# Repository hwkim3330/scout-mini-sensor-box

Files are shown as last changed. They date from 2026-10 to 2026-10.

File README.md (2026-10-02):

# SCOUT MINI OMNI Sensor / Compute Enclosure (KETI)

Single-source parametric CAD for a hexagonal sheet-metal box that sits on an AgileX **SCOUT MINI (OMNI)** robot and carries an **Ouster OS1** lidar, a **Jetson AGX Orin**, up to six **Arducam B0473** cameras, and the power/CAN electronics. REV 9 is the final version sent out for quotation (RFQ).

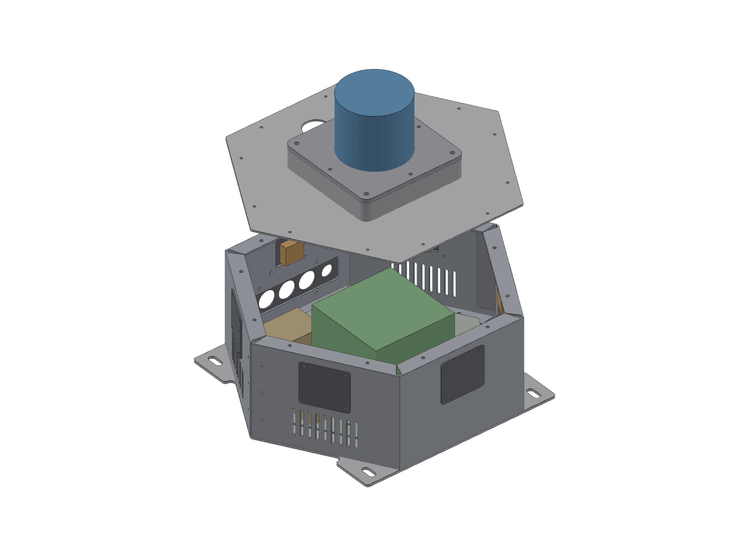
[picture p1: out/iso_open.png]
Exploded view


| | |
|---|---|
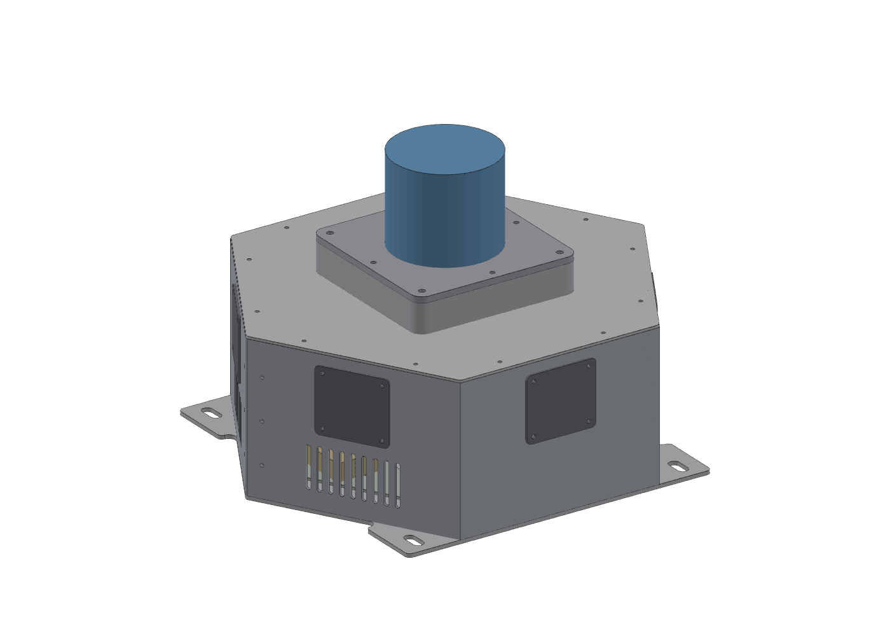
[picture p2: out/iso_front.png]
Front
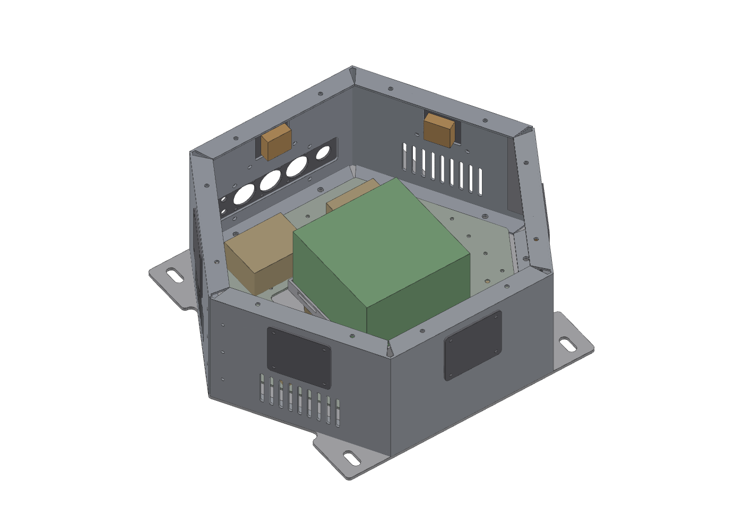
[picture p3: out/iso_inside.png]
Inside
|  |  |

## Design at a glance

- Hexagon 300 mm across flats, 130 mm tall; AL5052-H32 sheet (2 mm walls/cover, 3 mm floor), AL6061-T6 for the lidar plate and riser.
- Walls are two bent halves (C1–C3, C4–C6) joined by splice brackets, so each half fits a standard press brake.
- Self-clinching (PEM) fasteners throughout; bend allowances use Ri 2.0 / K 0.40, and the vendor re-flattens with their own bend deduction before cutting.
- Vents on C1/C3/C4/C6 for the AGX airflow, rear service panel on C5, removable electrical plate (P10).
- Sources for the mounting, power and thermal decisions are in [REFERENCES.md](REFERENCES.md).
- Items that depend on measuring real hardware (camera holder holes, OS1 pin pattern, rail slot pitch, DC/DC spec) are marked **HOLD**: those parts are delivered blank and finished in-house.

| Part | Name | Material / t |
|---|---|---|
| P01 | Bottom plate | AL5052 3.0 |
| P02 / P03 | Wall half, front / rear | AL5052 2.0 |
| P04 | Top cover | AL5052 2.0 |
| P05 | OS1 mount plate | AL6061 5.0 |
| P06 | Camera adapter plate (×8) | AL5052 2.0 |
| P07 | Rear service panel | AL5052 2.0 |
| P08 | AGX tray | AL5052 2.0 |
| P09 | Wall splice bracket (×2) | AL5052 2.0 |
| P10 | Electrical plate | AL5052 2.0 |
| P11 | OS1 riser frame | AL6061 25 |

## Files

`geom.py` is the only source of geometry. Everything in `out/` is generated from it:

| Script | Output |
|---|---|
| `geom.py` | all geometry: flat patterns, holes, PEM, bends |
| `model3d.py` | CadQuery 3D model → `out/step/*.step` |
| `dxfout.py` | laser-cut DXF → `out/dxf/*.dxf` (CUT / BEND / NOTE layers) |
| `drc.py` | design-rule check: PEM-to-edge and PEM-to-bend distance, hole spacing |
| `drawlib.py`, `sheets_a.py`, `sheets_b.py`, `build_pdf.py` | 10-sheet A3 drawing set → `out/SBOX_REV9_DRAWINGS.pdf` |
| `bom.py` | BOM / RFQ workbook → `out/SBOX_REV9_BOM.xlsx` |
| `shoot.py` + `web/render.html` | three.js renders → `out/*.png` (optional) |

## Rebuild

```bash
python3 -m venv .venv && . .venv/bin/activate
pip install -r requirements.txt

python3 model3d.py                          # STEP (+ out/tess.pkl for renders), ~30 s
python3 dxfout.py                           # DXF
python3 drc.py                              # must print "DRC issues: 0"
python3 build_pdf.py out/SBOX_REV9_DRAWINGS.pdf
python3 bom.py
```

Renders (optional; needs Node and Playwright):

```bash
(cd web && npm install) && pip install playwright && playwright install chromium
python3 shoot.py
```

The drawings need a Hangul font: Noto Sans CJK on Linux, Apple SD Gothic Neo on macOS, or Malgun Gothic on Windows is picked up automatically.

---

**한국어 요약:** SCOUT MINI 로봇 위에 올리는 육각 판금 센서/컴퓨트 박스(라이다 OS1, Jetson AGX Orin, 카메라 6대) 설계 소스입니다. `geom.py` 하나에서 STEP·DXF·도면 PDF·BOM이 모두 생성되고, REV 9는 견적용 최종판입니다.

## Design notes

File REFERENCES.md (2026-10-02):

# References

External material behind design decisions in REV 9, and what each one changes (or doesn't).

## Robot mounting and power

**AgileX SCOUT MINI R&D Kit Pro — user manual** ([PDF](https://static.generation-robots.com/media/scout-mini-pro-user-manual.pdf))
- The manufacturer's own sensor stack: stacked sheet-metal brackets (AGX Xavier → USB hub / USB-CAN / RealSense → voltage converters → lidar on top).
- Rail mounting: four slider nuts, two per rail, four screws. Same 4-point ear-slot method as P01.
- The manual gives no rail pitch, so **HOLD 2 stays open**.
- Power: separate 24→19 V (Xavier) and 24→12 V (lidar, hub, router) converters; the expansion port is limited to 24 V 5 A.
- CAN: USB-CAN at 500 kbps. This design uses CAN Pal on AGX J30 instead, which saves a USB port.

**Jetson AGX Orin DC input range** ([NVIDIA forum](https://forums.developer.nvidia.com/t/jeston-agx-orin-voltage-range/240687))
- The dev kit DC jack accepts 7–20 V. At 19 V the AGX draws about 3.2 A for 60 W, against 5 A at 12 V.
- Added to **HOLD 6** as an alternative: if the existing 24→12 V DC/DC can't do 8 A continuous, feed only the AGX from a separate 24→19 V converter. The 12 V rail then carries only the 5G modem (about 1 A).
- Check this against the carrier board documentation before buying a converter; the source is a forum answer.

**SCOUT MINI SolidWorks model** ([Saibts/AgileX-scout-mini-sw](https://github.com/Saibts/AgileX-scout-mini-sw), MIT)
- An unofficial model made for a ROS 2 simulation. The rails are plain blocks with no slot detail, so it can't settle the rail pitch either.
- The files are SolidWorks-only (`.SLDPRT`). If you open them in SolidWorks, the rail center distance is still only a rough cross-check.
- **HOLD 2 is released only by measuring the real robot or by the WeGo reply.**

## Lidar

**Ouster OS1 Rev7 hardware manual — mounting and thermal** ([docs](https://static.ouster.dev/sensor-docs/hw_user_manual_OS1/hw_common_sections_OS1/os1-overview.html))
- Recommends mounting on 6061 aluminium (167 W/m·K). P05 and P11 are AL6061-T6.
- Base and top should stay within +25 °C of ambient. Performance drops up to 20 % from 52 °C, and the sensor may shut down at 60 °C.
- Use a thermal pad (TIM) if the mounting surface is not flat. P05/P11 contact faces are left bare (no paint), and P11 has a 0.05 flatness callout.
- M3 screws; torque 120–146 cN·m for stainless.

## Thermal: AGX Orin in a closed box

**Orin in a sealed aluminium enclosure** ([MDPI Electronics 2026, 15(11) 2467](https://www.mdpi.com/2079-9292/15/11/2467))
- 190 × 154 × 60 mm aluminium box at MAXN, −20 to +40 °C ambient.
- A thermostat fan that turns on at 30 °C inside cut the inside-outside difference from about 30 °C to 5–7 °C.
- A real inference load (19 W) settled near 75 °C. A synthetic 36 W stress load throttled at 40 °C ambient.
- **Not in REV 9.** Candidate for REV 10: replace one exhaust vent (C1 or C6) with a 40 or 60 mm fan cutout plus a thermostat. REV 9 is the RFQ-final drawing set, so the change waits for the next revision. If the parts are already ordered, add a bolt-on fan bracket or post-machine the cutout instead.

## 360° camera layout (comparison only)

- [Stereolabs Robotics 360° Perception Kit](https://www.stereolabs.com/store/products/robotics-360-perception-kit): AGX Orin + 4 × ZED X, a commercial 360° kit.
- [360° surround view on AGX Orin](https://info-kevinjackson.medium.com/360-surround-view-camera-solution-using-nvidia-jetson-agx-orin-31d5c9511b3e): software side (stitching).

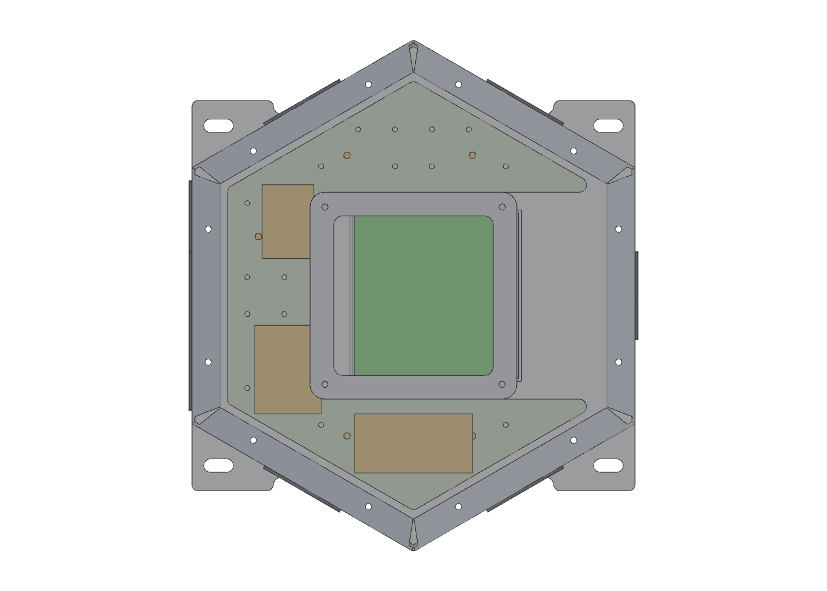
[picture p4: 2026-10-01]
out/top.png

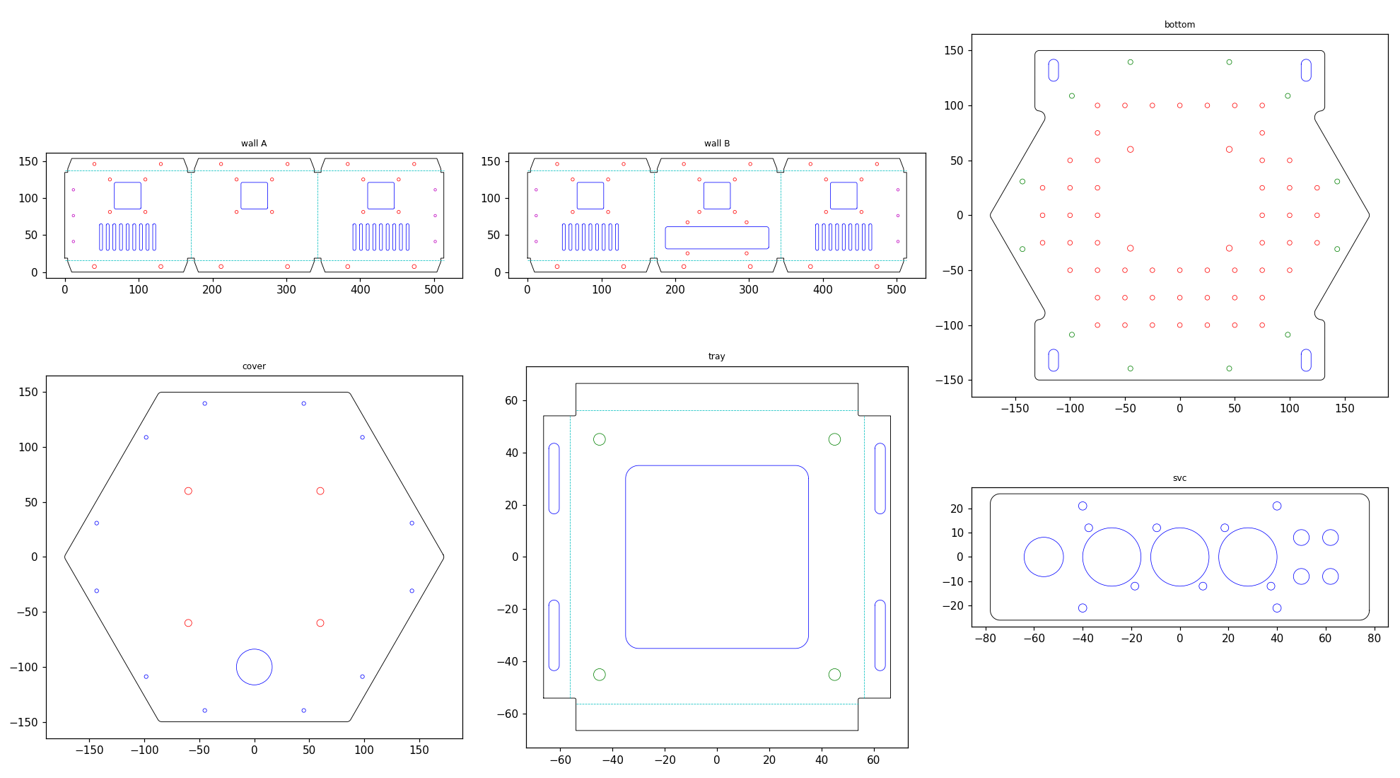
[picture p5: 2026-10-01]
out/preview.png

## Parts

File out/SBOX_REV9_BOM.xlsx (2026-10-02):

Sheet: FAB_PARTS
노란 칸 = 제작사 견적 입력. 질량 = 3D 모델 체적 × 2.68 g/cm³. 금액 = 수량 × 단가 (자동).
품번 | 품명 | 재질 | 두께 t(mm) | 수량 | 공정 | PEM / 후가공 | DXF | 단품 질량(g, 계산) | 단가 A 무처리(원) | 단가 B 분체도장(원) | 금액 A | 금액 B
P01 | BOTTOM PLATE | AL5052-H32 | 3 | 1 | Laser | CLSS-M4-2 ×10 (트레이 4 + 전장판 6), CSK ×12 | P01_BOTTOM_PLATE.dxf | 671
P02 | WALL HALF – FRONT (C1/C2/C3) | AL5052-H32 | 2 | 1 | Laser + Bend (2×60°, 2×90°) | CLSS-M3-1 ×18, CLSS-M4-1 ×6 | P02_WALL_HALF_FRONT.dxf | 394
P03 | WALL HALF – REAR (C4/C5/C6) | AL5052-H32 | 2 | 1 | Laser + Bend (2×60°, 2×90°) | CLSS-M3-1 ×22, CLSS-M4-1 ×6 | P03_WALL_HALF_REAR.dxf | 371
P04 | TOP COVER | AL5052-H32 | 2 | 1 | Laser | — (Ø5.5 ×4). 도장 시 P11 접촉부 140×140 MASK | P04_TOP_COVER.dxf | 411
P05 | OS1 MOUNT PLATE | AL6061-T6 | 5 | 1 | Laser / CNC + Tap | M5 TAP ×4 (B). OS1 접촉면 Ø100 + 하면 BARE MASK. OS1 홀 HOLD | P05_OS1_PLATE.dxf | 261
P06 | CAMERA ADAPTER PLATE | AL5052-H32 | 2 | 8 | Laser | — (lens/holder HOLD, KETI) | P06_CAMERA_PLATE.dxf | 17
P07 | REAR SERVICE PANEL | AL5052-H32 | 2 | 1 | Laser | — | P07_SERVICE_PANEL.dxf | 34
P08 | AGX TRAY | AL5052-H32 | 2 | 1 | Laser + Bend (4×90°) | CSK ×4. 70×70 = ADAPTER/CABLE CLEARANCE (HOLD 5, 그대로 가공) | P08_AGX_TRAY.dxf | 68
P09 | WALL SPLICE BRACKET | AL5052-H32 | 2 | 2 | Laser + Bend (1×60°) | — | P09_SPLICE_BRACKET.dxf | 23
P10 | ELECTRICAL PLATE (탈착식) | AL5052-H32 | 2 | 1 | Laser | — (Ø3.4 그리드, PEM 없음) | P10_ELEC_PLATE.dxf | 156
P11 | OS1 RISER FRAME | AL6061-T6 | 25 | 1 | CNC + Tap (M5 ×8, 10DP) | 무처리 BARE (도장/아노다이징 금지), 평면도 0.05 | P11_OS1_RISER.dxf (외형 참고) + 도면 SHEET 8 | 532
 | 합계 |  |  |  |  | PEM 총계 = 10 + 24 + 28 = 62 ea (REV8 114)
표면처리 [A] 무처리 / [B] 흑색 분체도장 — 열접촉면 BARE 마스킹: P05 상면 Ø100 + 하면, P11 전체 무처리, P04 상면 140×140. 공차·검사: 도면 SHEET 1, 10.

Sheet: PURCHASED
노란 칸 = 입력. 주문 수량 = 필요 + 예비 (자동). 구매처 예: 미스미코리아 / 나사몰 / 디바이스마트 / 엘레파츠.
구분 | 품목 | 규격/재질 | 필요 수량 | 예비 | 주문 수량 | 사용처 | 비고 | 단가(원) | 금액(원) | 구매처
FASTENER | M3×8 버튼헤드 (ISO 7380) | SUS304 A2 | 40 | 10 |  | 커버 12, 카메라 24, 서비스 4
FASTENER | M4×8 접시머리 육각홈 (ISO 10642) | SUS304 A2 | 16 | 4 |  | 하판 12, 트레이 4
FASTENER | M5×12 육각홈 (ISO 4762) + 평와셔 M5 | SUS304 A2 | 4 | 2 |  | P05 → P11 탭 A
FASTENER | M5×10 육각홈 (ISO 4762) + 평와셔 M5 | SUS304 A2 | 4 | 2 |  | P04 하면 → P11 탭 B | 직결 옵션 시 → P05 탭 B
FASTENER | M8×16 육각홈 (ISO 4762) + 평와셔 M8 (ISO 7089) | SUS304 A2 | 4 | 2 |  | 레일 이어 슬롯 | 규격·길이 = 레일 확인 후 (HOLD 2)
FASTENER | SCOUT 레일 T-너트 M8 | 레일 규격 따름 | 4 | 2 |  | 레일 | HOLD 2 — 레일 피치·홈 폭 확인
FASTENER | M3×10 육각홈 + M3 나일록 너트 + 와셔 | SUS304 A2 | 6 | 4 |  | D-size 커넥터 ×3
FASTENER | M4 육각 스탠드오프 M-F 25 (수 6) | Al 또는 황동 | 4 | 0 |  | AGX 트레이 | 30/35는 B0473 fit check 결과 (HOLD 5)
FASTENER | M4 육각 스탠드오프 M-F 30 / 35 | Al 또는 황동 | 8 | 0 |  | AGX 트레이 높이 조정 | 옵션
FASTENER | 블라인드 리벳 Ø3.2 돔헤드, 그립 3.0~4.8 | Al/Al | 12 | 8 |  | 벽 스플라이스 | 제작사 조립 시 제작사 지급 가능
FASTENER | M4 육각 스탠드오프 M-F 10 (수 6) | Al 또는 황동 | 6 | 2 |  | P10 전장판
FASTENER | M4×8 버튼헤드 (ISO 7380) | SUS304 A2 | 6 | 2 |  | P10 → 스탠드오프
FASTENER | M3 볼트 + 나일론 스페이서 + 나일록 너트 키트 | Nylon/SUS | 1 | 0 |  | P10 부품 (DC/DC, CAN Pal, WAGO, 5G) | M3 6~20mm
FASTENER | M3×8 육각홈 (OS1 장착) | SUS / 12.9 | 4 | 2 |  | OS1 → P05 | 길이: OS1 나사 깊이 확인 (HOLD 3)
FASTENER | M2×6 + 너트/스페이서 (카메라 모듈) | SUS | 24 | 8 |  | B0473 ×6 → P06 | HOLD 4
CONNECTOR | 케이블 글랜드 M16×1.5 + 로크너트 (클램프 4.5~10) | 니켈황동 IP68 (예: Lapp SKINTOP MS-M 16) | 1 | 1 |  | P07 — SCOUT 확장 케이블 | 케이블 외경 확인
CONNECTOR | 분할형 케이블 글랜드 M32 (커넥터 통과형) | IP54 이상 | 1 | 0 |  | P04 — OS1 케이블 | OS1 케이블 외경/커넥터 확인
CONNECTOR | etherCON 피드스루 D-size (Neutrik NE8FDP 또는 동등) | Cat6 | 1 | 0 |  | P07 D1
CONNECTOR | USB 3.0 A↔A 피드스루 D-size (Neutrik NAUSB3 또는 동등) |  | 1 | 0 |  | P07 D2
CONNECTOR | D-size 블랭크 플레이트 / 12V DC 잭 D-size |  | 1 | 0 |  | P07 D3 | 선택
CONNECTOR | SMA 벌크헤드(F) – U.FL/IPEX 피그테일 15cm | 50Ω | 4 | 0 |  | P07 SMA | 5G 모뎀 확정 후 (HOLD 7)
ELECTRICAL | SCOUT 확장 케이블: 4핀 항공 메이팅 플러그 + 4C 케이블 (AWG18 ×2 + 트위스트 CAN) 1 m | 플러그 규격 위고 확인 | 1 | 0 |  | H1 | 확보 방법 위고 문의 중 (구매 또는 KETI 납땜)
CABLE | Arducam 15-22pin FPC 60cm | Arducam 정품 | 2 | 1 |  | 먼 2면 카메라 | 기본 30cm ×6 동봉, 60cm 별도
ELECTRICAL | ATO 인라인 퓨즈홀더 AWG16~18 + ATO 5A 퓨즈 |  | 1 | 2 |  | 24V 인입 | 퓨즈 예비 2
ELECTRICAL | WAGO 221-413 레버 커넥터 | 3P | 4 | 2 |  | 24V/GND 분배
ELECTRICAL | 전선 AWG18 적/흑 | UL1015 | 3 | 0 |  | 전원 (m) | 단위 m
ELECTRICAL | 트위스트 페어 AWG24 |  | 1 | 0 |  | CAN (m) | 단위 m
ELECTRICAL | DC 배럴 플러그 5.5/2.5 피그테일 | 센터 + | 1 | 1 |  | AGX J41
ELECTRICAL | DC/DC 24→12V (기존품 사양 미달 시에만 대체) | 입력 19~36V, 12V 연속 ≥8A (예: Mean Well SD-100B-12) | 0 | 0 |  | P10 장착 | HOLD 6 — 기존품 실측 후 수량 결정
ELECTRICAL | 듀폰 점퍼 F-F 20cm |  | 4 | 4 |  | CAN Pal ↔ J30
MISC | EPDM 폼 테이프 10×3 (점착) |  | 2 | 0 |  | 커버·하판 가스켓 (m) | 옵션 방진
MISC | EPDM 패드 1t 110×110 |  | 1 | 0 |  | AGX 트레이
MISC | 벨크로 스트랩 25mm × 300 |  | 2 | 1 |  | AGX 고정
MISC | 케이블 타이 + 타이 마운트 (M3) |  | 20 | 0 |  | 하네스
MISC | 나사 고착제 중강도 (Loctite 243 등) |  | 1 | 0
OPTION | OPT-2 벤트 방진 메쉬 (SUS 100mesh, 내측 접착) |  | 4 | 0 |  | C1/C3/C4/C6 벤트 | 분진 환경 시
 | 합계

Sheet: HOLD
# | HOLD 항목 | 해제 방법 | 판금 발주 영향 | 담당 | 완료일
1 | SCOUT 4핀 항공 메이팅 플러그 규격 | 위고 문의 → 플러그+케이블 확보 후 M16 글랜드 통과 | 없음 | 위고/KETI
2 | 레일 피치 230 / 홈 폭 / T-너트 | 매뉴얼 5.2 도면·실측·위고 회신으로 확정 | P01 슬롯 가공 전 필수 | KETI
3 | OS1 4×M3 + Ø2 핀 패턴 | 보유 OS1 실측/템플릿 → P05 후가공 | P05 블랭크 납품 | KETI
4 | B0473 홀더 홀/렌즈 위치 | 납품 키트 실측 → P06 후가공 | P06 블랭크 납품 | KETI
5 | B0473 어댑터 FIT CHECK | AGX 카메라 커넥터(J509) 결합 후 하부 돌출/케이블 경로 확인 → P08 70×70 유지·축소, 스탠드오프 25/30/35 | 없음 (P08 그대로 가공) | KETI
6 | 기존 24→12V DC/DC 실물 사양 | 12V 연속 ≥8A, 피크 ≥10A, 효율 ≥90% 확인 전 전원 확정 금지. 미달 시 AGX만 24→19V 별도 변환기 가능 (AGX 입력 7~20V, 60W ≈ 3.2A) | 없음 (P10 장착) | KETI
7 | 5G 모뎀/안테나 | 모델 확정 → P10 장착, SMA 4홀 기가공 | 없음 | KETI

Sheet: RFQ
[견적 요청] KETI 모빌리티플랫폼연구센터 — SCOUT MINI 센서/컴퓨트 박스 판금 (REV 9, 최종)
1. 품목: P01~P11 (FAB_PARTS 시트), 1세트 (P06 8개, P09 2개). 옵션 수량 3세트 / 5세트 단가 병기 요청.
2. 재질: AL5052-H32 2.0T / 3.0T, AL6061-T6 5.0T (P05), AL6061-T6 25T (P11, CNC).
3. 공정: 레이저 → PEM 압입 (PennEngineering CLSS 또는 동등, 62개) → 절곡 → 벽 링 리벳 조립 (P02+P03+P09). P05/P11 탭, P11 CNC.
4. 표면: [A] 무처리, [B] 흑색 분체도장 — 분리 견적. 열접촉면 BARE: P05 상면 Ø100·하면, P11 전체, P04 140×140.
5. 첨부: 도면 PDF 10매, DXF 11종 (외형·홀 MASTER), STEP (조립/부품), 본 BOM.
6. 요청: 견적서 (A/B), 납기, 제작사 BD 반영 재전개 DXF 사전 회신, 첫 절곡품(벽 1면) 치수 확인 후 본 가공.
7. 검사: 도면 SHEET 9 출하검사 항목 (AF300±0.5, H125±0.3, 플랜지 19±0.3, PEM 전수, 가조립 체결).
8. 제외: 체결류·커넥터·장치 (PURCHASED 시트, 별도 구매). 장치 종속 홀 (HOLD) 가공 제외.
9. 문의: hwkim3@keti.re.kr

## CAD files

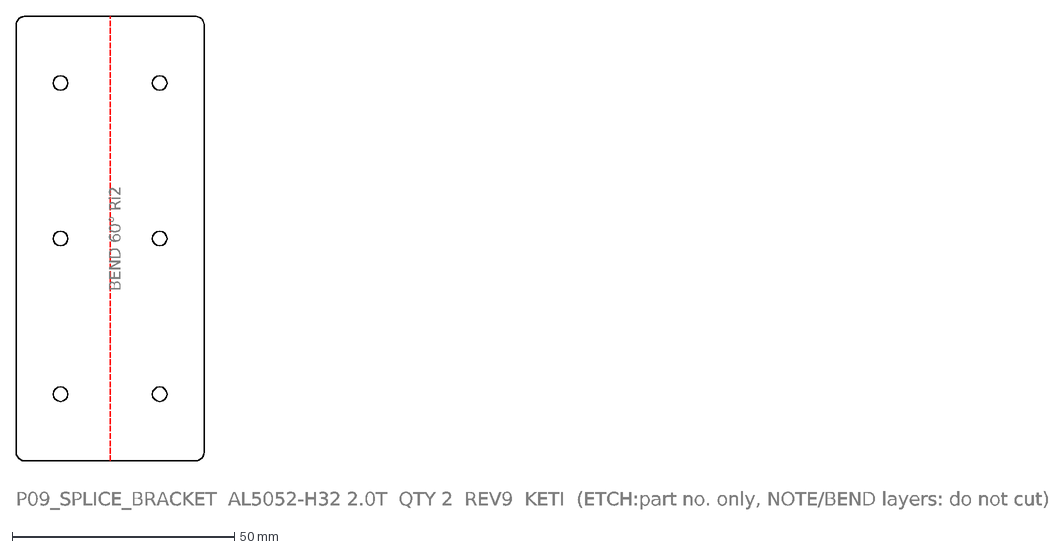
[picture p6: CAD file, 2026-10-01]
out/dxf/P09_SPLICE_BRACKET.dxf
BEND 60° Ri2
P09_SPLICE_BRACKET AL5052-H32 2.0T QTY 2 REV9 KETI (ETCH:part no. only, NOTE/BEND layers: do not cut)

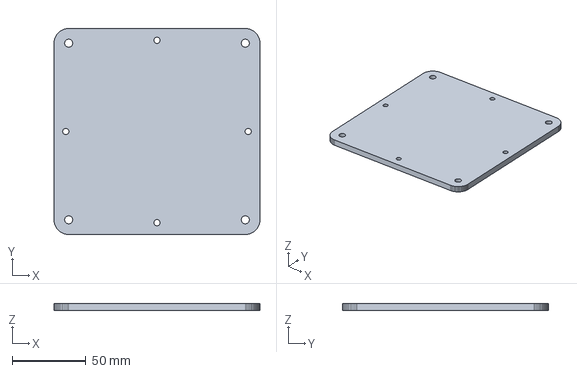
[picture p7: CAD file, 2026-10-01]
out/step/P05_OS1_PLATE.step
140.0 x 140.0 x 5.00 mm

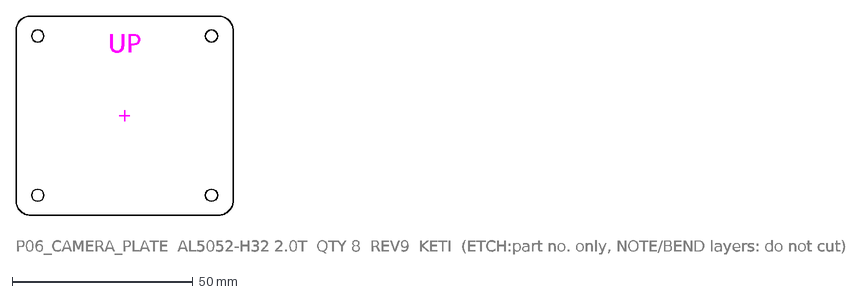
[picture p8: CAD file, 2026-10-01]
out/dxf/P06_CAMERA_PLATE.dxf
UP
P06_CAMERA_PLATE AL5052-H32 2.0T QTY 8 REV9 KETI (ETCH:part no. only, NOTE/BEND layers: do not cut)

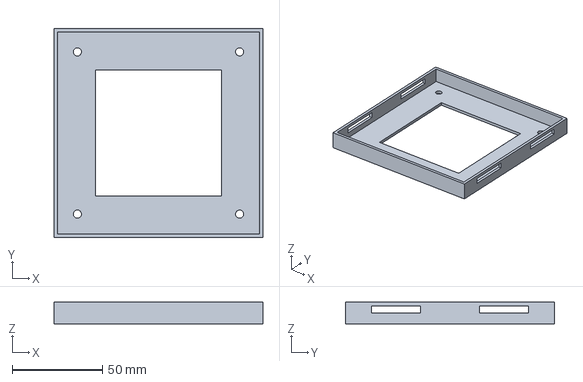
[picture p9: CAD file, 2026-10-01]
out/step/P08_AGX_TRAY.step
116.0 x 116.0 x 12.0 mm

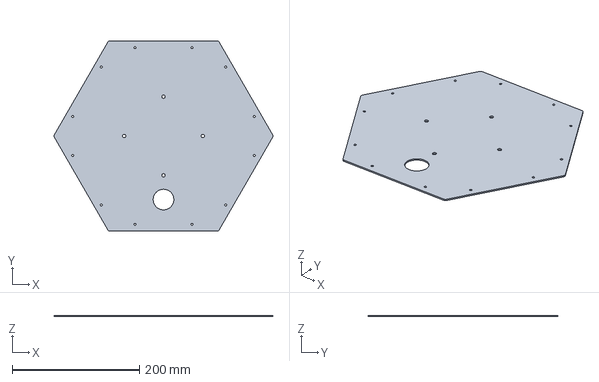
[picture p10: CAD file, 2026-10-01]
out/step/P04_TOP_COVER.step
344.6 x 299.5 x 2.00 mm

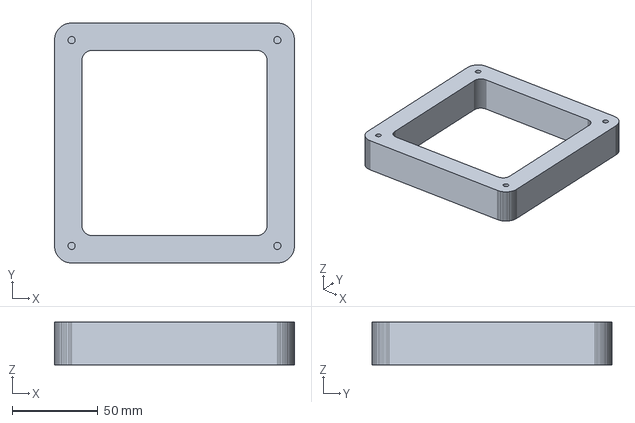
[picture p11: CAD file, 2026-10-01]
out/step/P11_OS1_RISER.step
140.0 x 140.0 x 25.0 mm

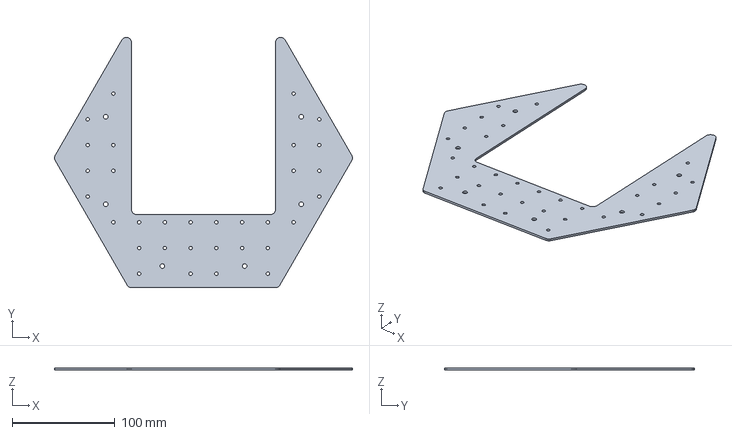
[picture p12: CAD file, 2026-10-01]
out/step/P10_ELEC_PLATE.step
289.4 x 243.1 x 2.00 mm

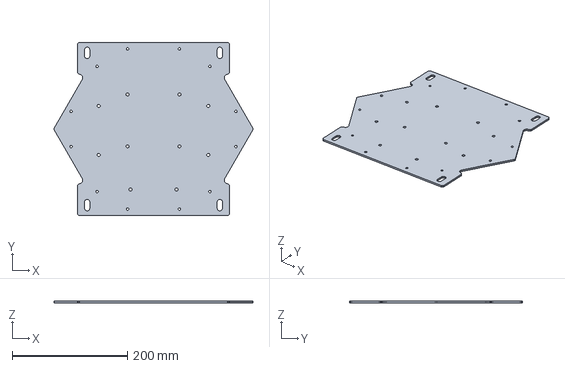
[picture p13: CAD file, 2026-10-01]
out/step/P01_BOTTOM_PLATE.step
345.2 x 300.0 x 3.00 mm

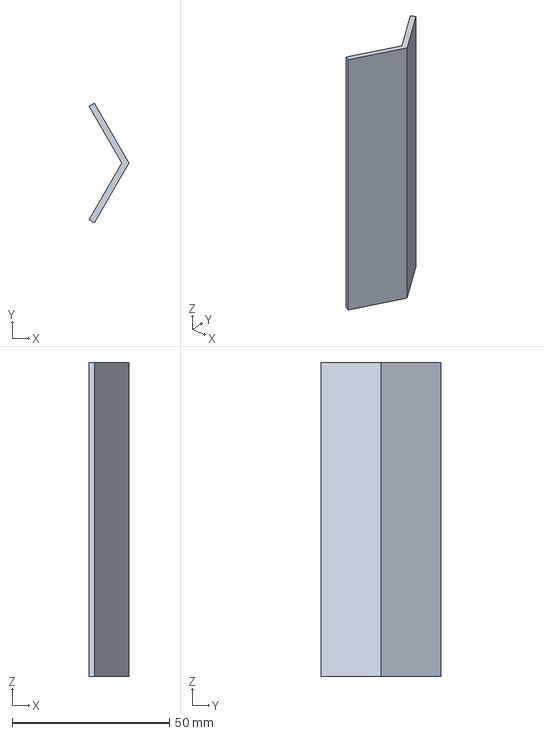
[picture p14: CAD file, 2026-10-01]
out/step/P09_SPLICE.step
12.7 x 38.1 x 100.0 mm

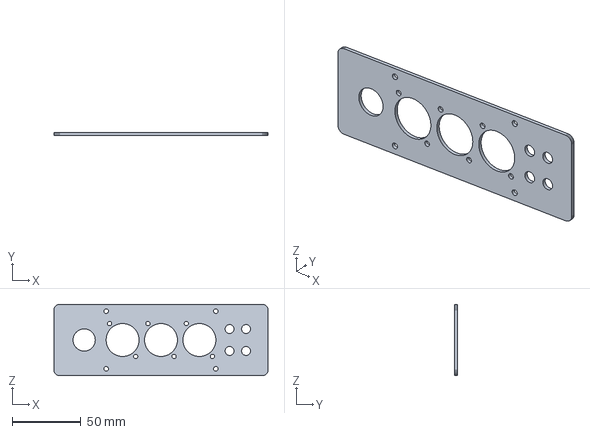
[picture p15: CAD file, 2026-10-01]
out/step/P07_SERVICE_PANEL.step
156.0 x 2.00 x 52.0 mm

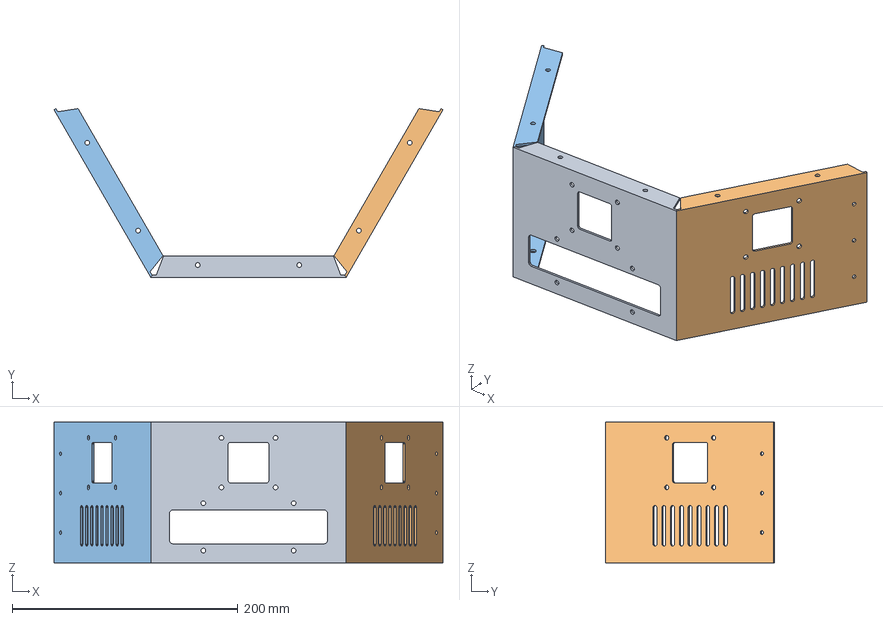
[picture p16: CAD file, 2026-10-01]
out/step/P03_WALL_HALF_REAR.step
344.9 x 149.7 x 125.0 mm

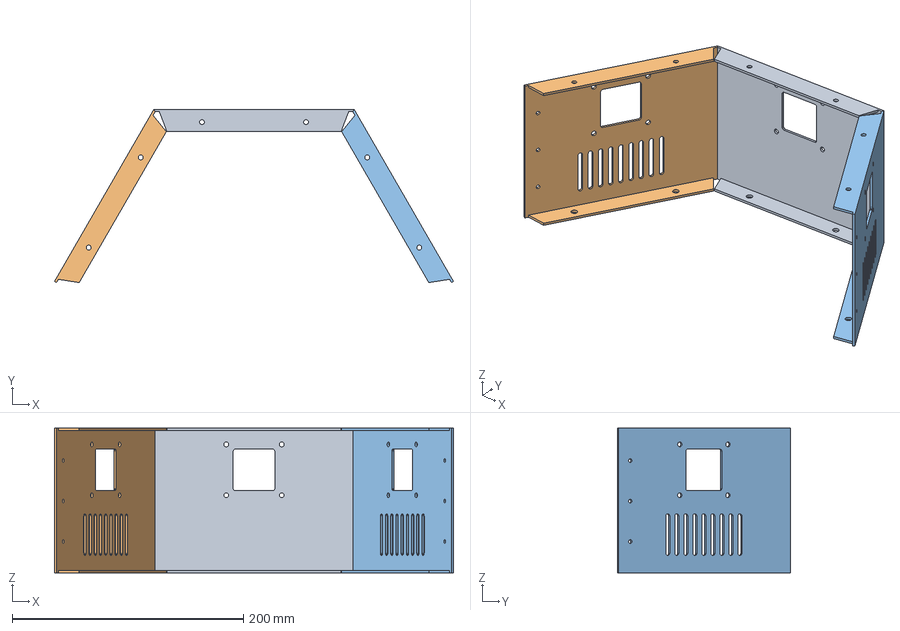
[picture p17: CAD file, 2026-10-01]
out/step/P02_WALL_HALF_FRONT.step
344.9 x 149.7 x 125.0 mm

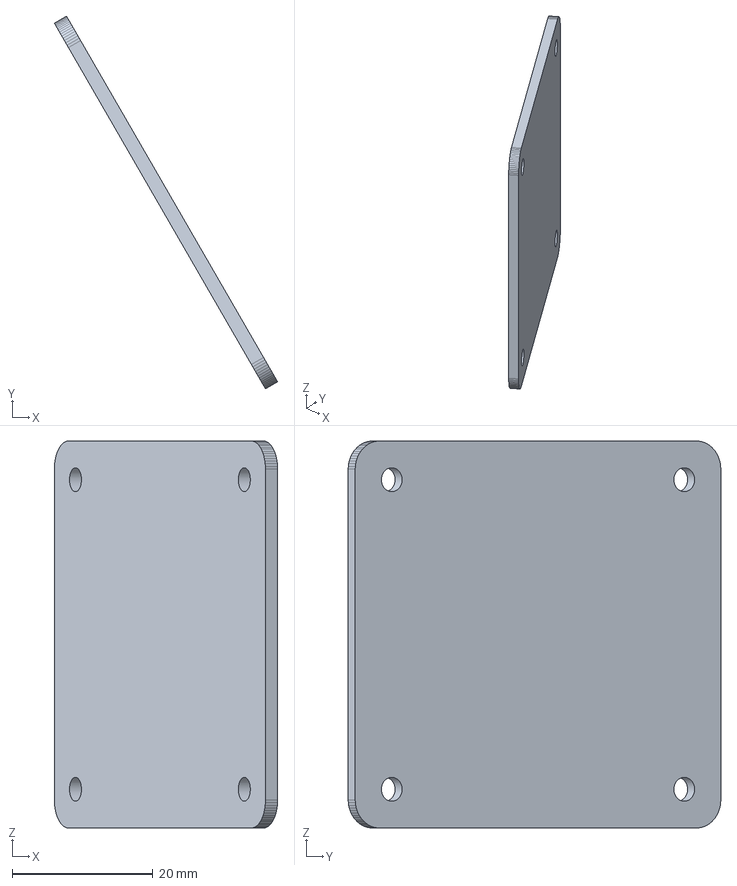
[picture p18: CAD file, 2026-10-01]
out/step/P06_CAM_PLATE.step
31.7 x 53.0 x 55.0 mm

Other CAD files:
out/dxf/P01_BOTTOM_PLATE.dxf
out/dxf/P02_WALL_HALF_FRONT.dxf
out/dxf/P03_WALL_HALF_REAR.dxf
out/dxf/P04_TOP_COVER.dxf
out/dxf/P05_OS1_PLATE.dxf
out/dxf/P07_SERVICE_PANEL.dxf
out/dxf/P08_AGX_TRAY.dxf
out/dxf/P10_ELEC_PLATE.dxf
out/dxf/P11_OS1_RISER.dxf

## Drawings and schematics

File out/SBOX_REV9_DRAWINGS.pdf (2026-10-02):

1 | 2 | 3 | 4 | 5 | 6 | 7 | 8

F

E

D

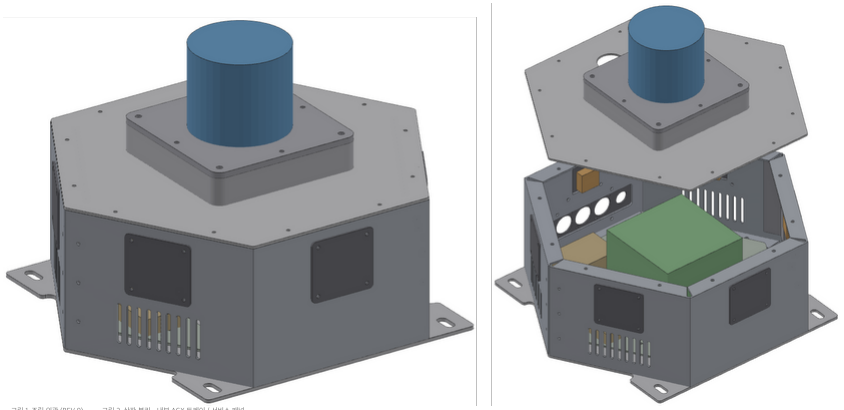
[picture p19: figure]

C

B

A

SENSOR / COMPUTE ENCLOSURE — 제작 도면 세트 (RFQ RELEASE) | SCOUT MINI OMNI / Jetson AGX Orin / Arducam B0473 / Ouster OS1

DIMENSIONS IN mm · 3RD ANGLE PROJECTION · DO NOT SCALE · DXF = MASTER FOR CUT GEOMETRY · 도면/DXF 상이 시 문의

그림 1. 조립 외관 (REV 9) | 그림 2. 상판 분리 – 내부 AGX 트레이 / 서비스 패널
품번 | 품명 | 재질 / 두께 | 수량 | 가공 | 인서트 / 표면
P01 | BOTTOM PLATE | AL5052-H32 3.0T | 1 | LASER | CLSS-M4-2 ×10, CSK ×12
P02 | WALL HALF – FRONT | AL5052-H32 2.0T | 1 | LASER + BEND 4 | CLSS-M3-1 ×18, M4-1 ×6
P03 | WALL HALF – REAR | AL5052-H32 2.0T | 1 | LASER + BEND 4 | CLSS-M3-1 ×22, M4-1 ×6
P04 | TOP COVER | AL5052-H32 2.0T | 1 | LASER | — (P11 접촉부 MASK)
P05 | OS1 MOUNT PLATE | AL6061-T6 5.0T | 1 | LASER/CNC + TAP | M5 TAP ×4, 접촉면 BARE
P06 | CAMERA ADAPTER PLATE | AL5052-H32 2.0T | 8 | LASER | — (6 + 2 spare)
P07 | REAR SERVICE PANEL | AL5052-H32 2.0T | 1 | LASER | —
P08 | AGX TRAY | AL5052-H32 2.0T | 1 | LASER + BEND 4 | CSK ×4
P09 | WALL SPLICE BRACKET | AL5052-H32 2.0T | 2 | LASER + BEND 1 | —
P10 | ELECTRICAL PLATE (탈착) | AL5052-H32 2.0T | 1 | LASER | — (Ø3.4 GRID)
P11 | OS1 RISER FRAME | AL6061-T6 25T | 1 | CNC + TAP | M5 TAP ×8, 무처리 BARE

PEM 합계 62개 (REV8 114개). 구매품 전체 목록: SBOX_REV9_BOM.xlsx

SHEET | CONTENTS
1 | INDEX / GENERAL NOTES / REVISION
2 | GENERAL ASSEMBLY (치수·인터페이스)
3 | P01 BOTTOM PLATE
4 | P02 WALL HALF – FRONT (전개/성형)
5 | P03 WALL HALF – REAR + SERVICE OPENING
6 | P04 TOP COVER / P05 OS1 PLATE
7 | P06 / P07 / P08 / P09 SMALL PARTS
8 | P10 ELECTRICAL PLATE / P11 OS1 RISER + FOV
9 | INTERNAL LAYOUT / WIRING / POWER BUDGET
10 | HARNESS / HOLD / INSPECTION / RFQ

## GENERAL NOTES / 일반 주기

1. 단위 mm. 레이저 외형·홀 좌표는 DXF가 기준(MASTER), 성형 치수·공차·후가공은 본 도면이 기준.
2. 일반공차 ISO 2768-m. 레이저 외형/홀 ±0.1, 절곡 성형치수 ±0.3, 절곡각 ±0.5°, 평면도 0.5/100.
3. 절곡 내R 2.0 (2T). DXF 전개는 K=0.40 참고치 — 제작사 금형 BD로 재전개 허용 (성형 외곽·홀 위치 유지).
4. PEM: PennEngineering CLSS(스테인리스) 또는 동등품, 절곡 전 압입. 총 62개.
5. 버 제거, 외곽 C0.3~0.5. 케이블/벤트 슬롯 버 제거 철저(FPC·케이블 손상 방지).
6. 표면: [A] 무처리 기본 견적 + [B] 흑색 분체도장 옵션 별도 견적 (PEM/탭 나사부 마스킹).

6a. 열접촉면 분체도장 금지 (BARE AL 마스킹): P05 상면 OS1 접촉부 Ø100 + P05 하면 전체,

P11 전체 무처리, P04 상면 P11 접촉부 140×140. — THERMAL CONTACT SURFACE KEEP BARE ALUMINUM

7. P02+P03+P09 리벳 조립(벽 링) 및 P01/P04 가조립 체결 확인까지 제작사 범위.
8. 장치 실측 종속 홀(OS1·카메라 홀더)은 발주 제외 — 블랭크 납품. P01 레일 슬롯은 피치 확인(HOLD 2) 후 가공.

## REVISION HISTORY

REV 8 → REV 9 변경 (견적 최종판)

a) P08 중앙 70×70: 'ADAPTER / CABLE CLEARANCE — HOLD UNTIL B0473 ADAPTER FIT CHECK'로 재정의.

REV8의 'J509 하부' 표기 삭제 (J509 = 캐리어보드 상면, 모듈 하부 영역 카메라 커넥터 — 어댑터 직결).

b) P01 M3 PEM 그리드 54개 삭제 → M4 PEM 6개 + 탈착식 전장판 P10 (Ø3.4 레이저 그리드). PEM 114 → 62.
c) OS1: P05 → P11 AL6061 25T 라이저 프레임 → P04. 하향 −22.5° 전 범위 확보 (가림 경계 −23.8°).

P04 M5 PEM 삭제 → 하면 M5 볼트. 라이저 제거 직결 옵션 유지 (P05 탭 B, 가림 경계 −15.4°).

d) P05 / P11 / P04 열접촉면 분체도장 금지 (BARE AL).
e) 전원 HOLD 6 유지 (기존 DC/DC 연속 ≥8A 확인 전 확정 금지). CAN: J30 p29/p31, CAN Pal 3.3V 구동 확정.

REV 8: 레일 슬롯 외부 이어(Y±132), 2분할 절곡 벽, HOLD 블랭크화, 서비스 패널 확정, 전원 예산

REV 7: 개념 GA / 배선 / 하네스 (제작 불가)

## 발주 범위 / SCOPE OF SUPPLY

[제작사 범위] P01~P11 레이저·절곡·CNC·탭·PEM 압입·버 제거·각인

+ 벽 링 리벳 조립(P02+P03+P09) + P01/P04 가조립 체결 확인

+ 표면처리 옵션 [B] 견적 분리 (6a 마스킹 포함)

[납품] 개별 포장, 벽 링은 조립 상태. 체결류(BOM 구매품)는 제외

[제외] 장치 종속 홀(HOLD) 후가공, 전장/하네스, 장치 조립

[제출 요청] 견적서(A/B 구분) · 납기 · 재전개 DXF(BD 반영)

- 첫 절곡품 치수 확인서(AF300, H125, 플랜지 19, 홀 피치)

[검사] SHEET 10 INSPECTION 항목 기준

KETI Mobility Platform Research Center | PROJECT: SCOUT-OMNI-SBOX

PART NO.

### ASSY-SBOX-R9

MATERIAL

see part list

QTY

1 set

SCALE

AS NOTED

TITLE

DRAWING INDEX / GENERAL NOTES

FINISH

RAW / OPT. BLACK P/C

REV

9

SHEET

DRAWN

hwkim3 / KETI

TOL.

ISO 2768-m (UNO)

DATE

2026-10-01

STATUS

RFQ FINAL

## TOP VIEW (FRONT = +Y = C2) 1:3

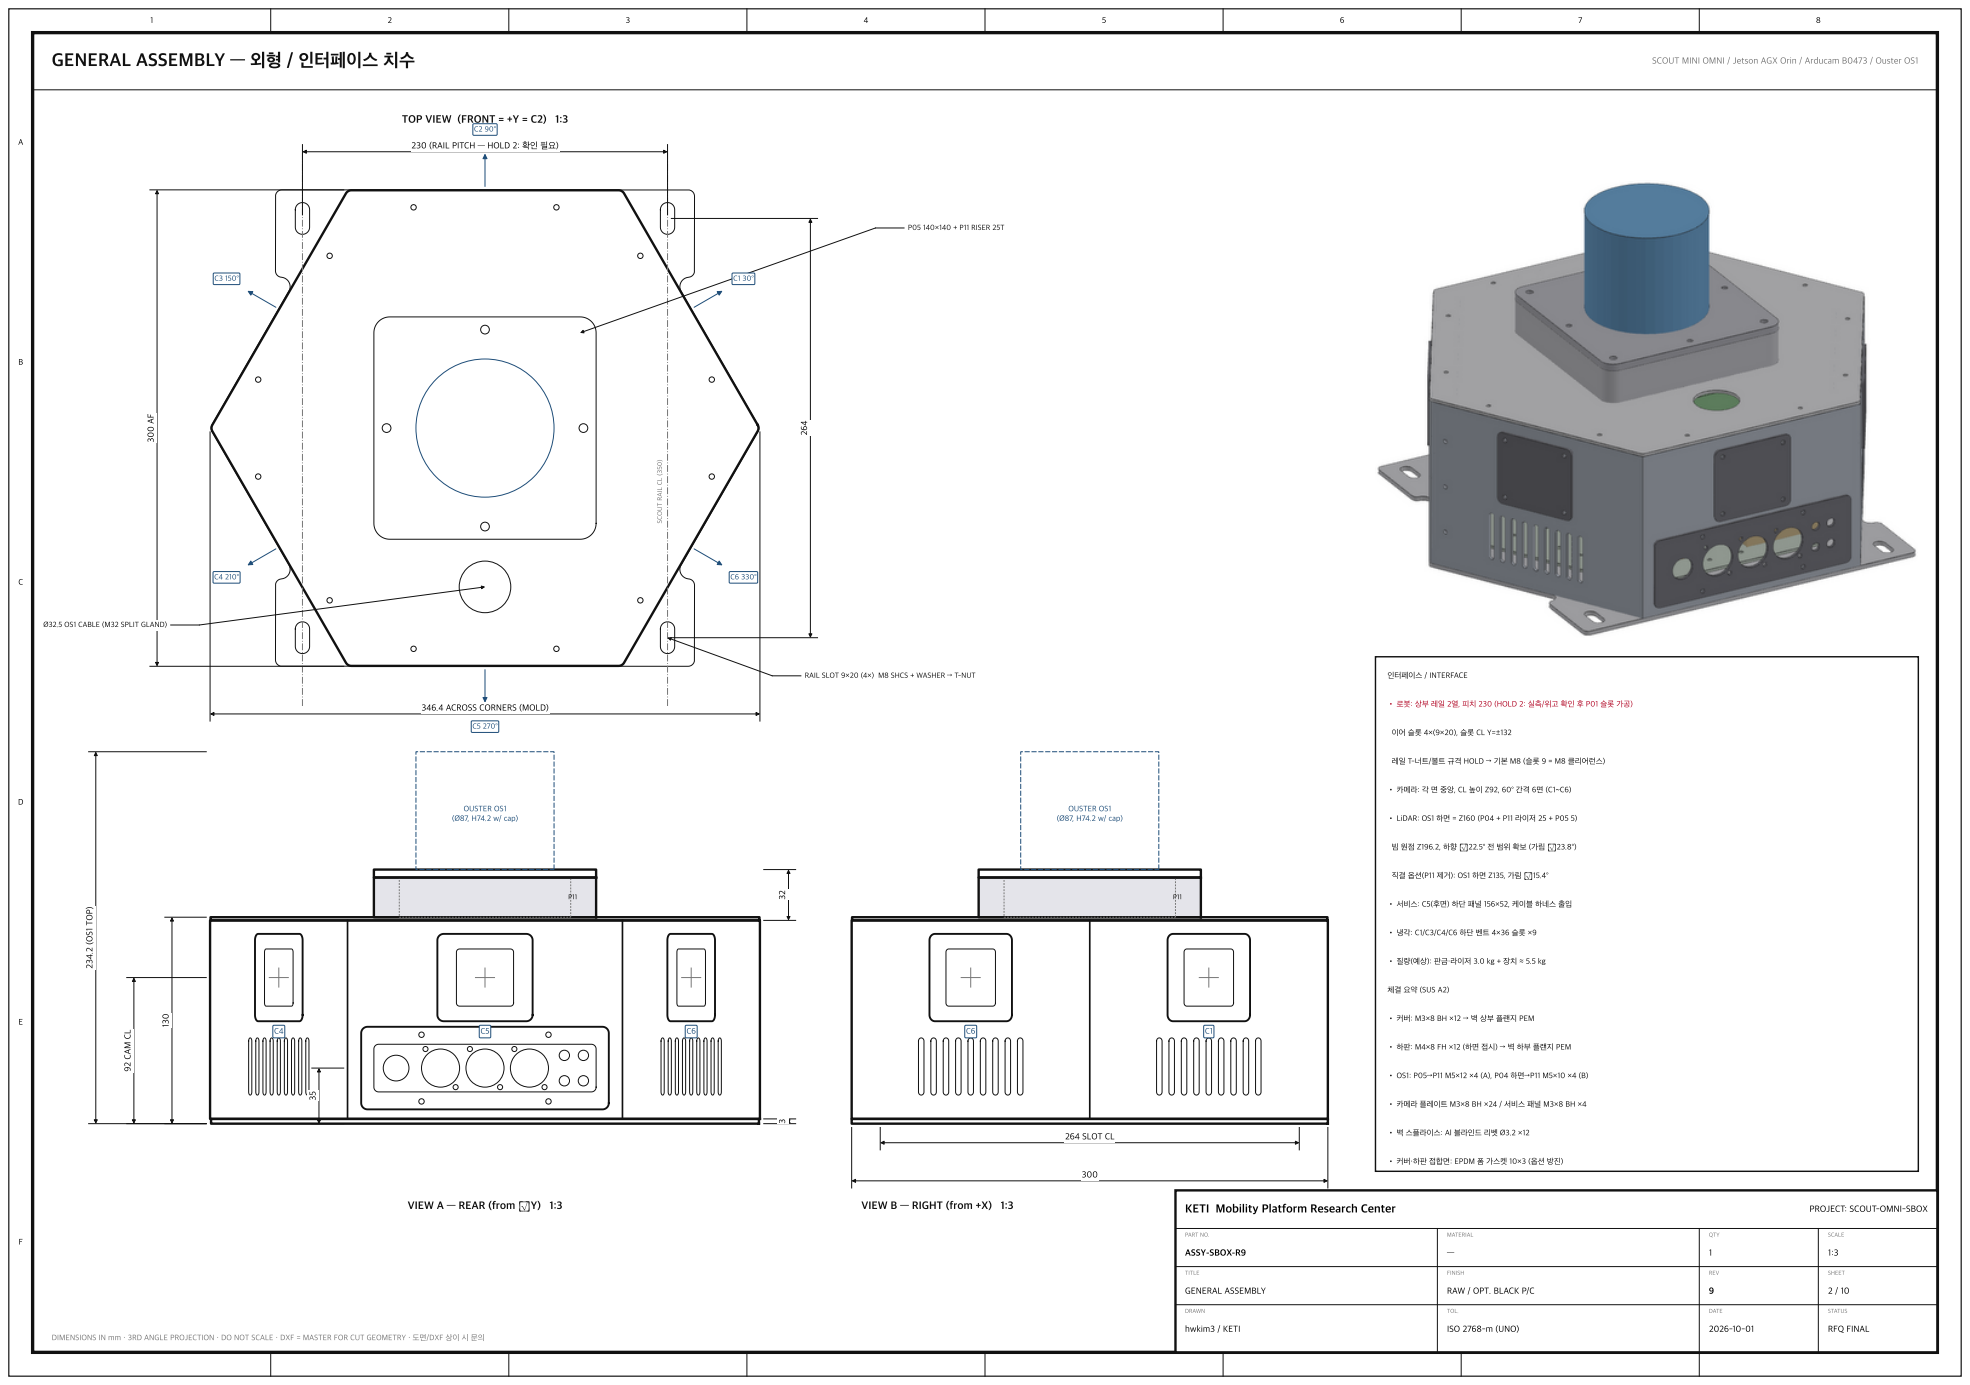
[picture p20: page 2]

230 (RAIL PITCH — HOLD 2: 확인 필요)

RAIL SLOT 9×20 (4×) M8 SHCS + WASHER → T-NUT

• 로봇: 상부 레일 2열, 피치 230 (HOLD 2: 실측/위고 확인 후 P01 슬롯 가공)

레일 T-너트/볼트 규격 HOLD → 기본 M8 (슬롯 9 = M8 클리어런스)

• 카메라: 각 면 중앙, CL 높이 Z92, 60° 간격 6면 (C1~C6)

• 서비스: C5(후면) 하단 패널 156×52, 케이블 하네스 출입

• 질량(예상): 판금·라이저 3.0 kg + 장치 ≈ 5.5 kg

• 커버: M3×8 BH ×12 → 벽 상부 플랜지 PEM

• 하판: M4×8 FH ×12 (하면 접시) → 벽 하부 플랜지 PEM

• 카메라 플레이트 M3×8 BH ×24 / 서비스 패널 M3×8 BH ×4

• 벽 스플라이스: Al 블라인드 리벳 Ø3.2 ×12

• 커버·하판 접합면: EPDM 폼 가스켓 10×3 (옵션 방진)
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

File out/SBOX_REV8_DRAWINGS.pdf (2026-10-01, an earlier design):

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

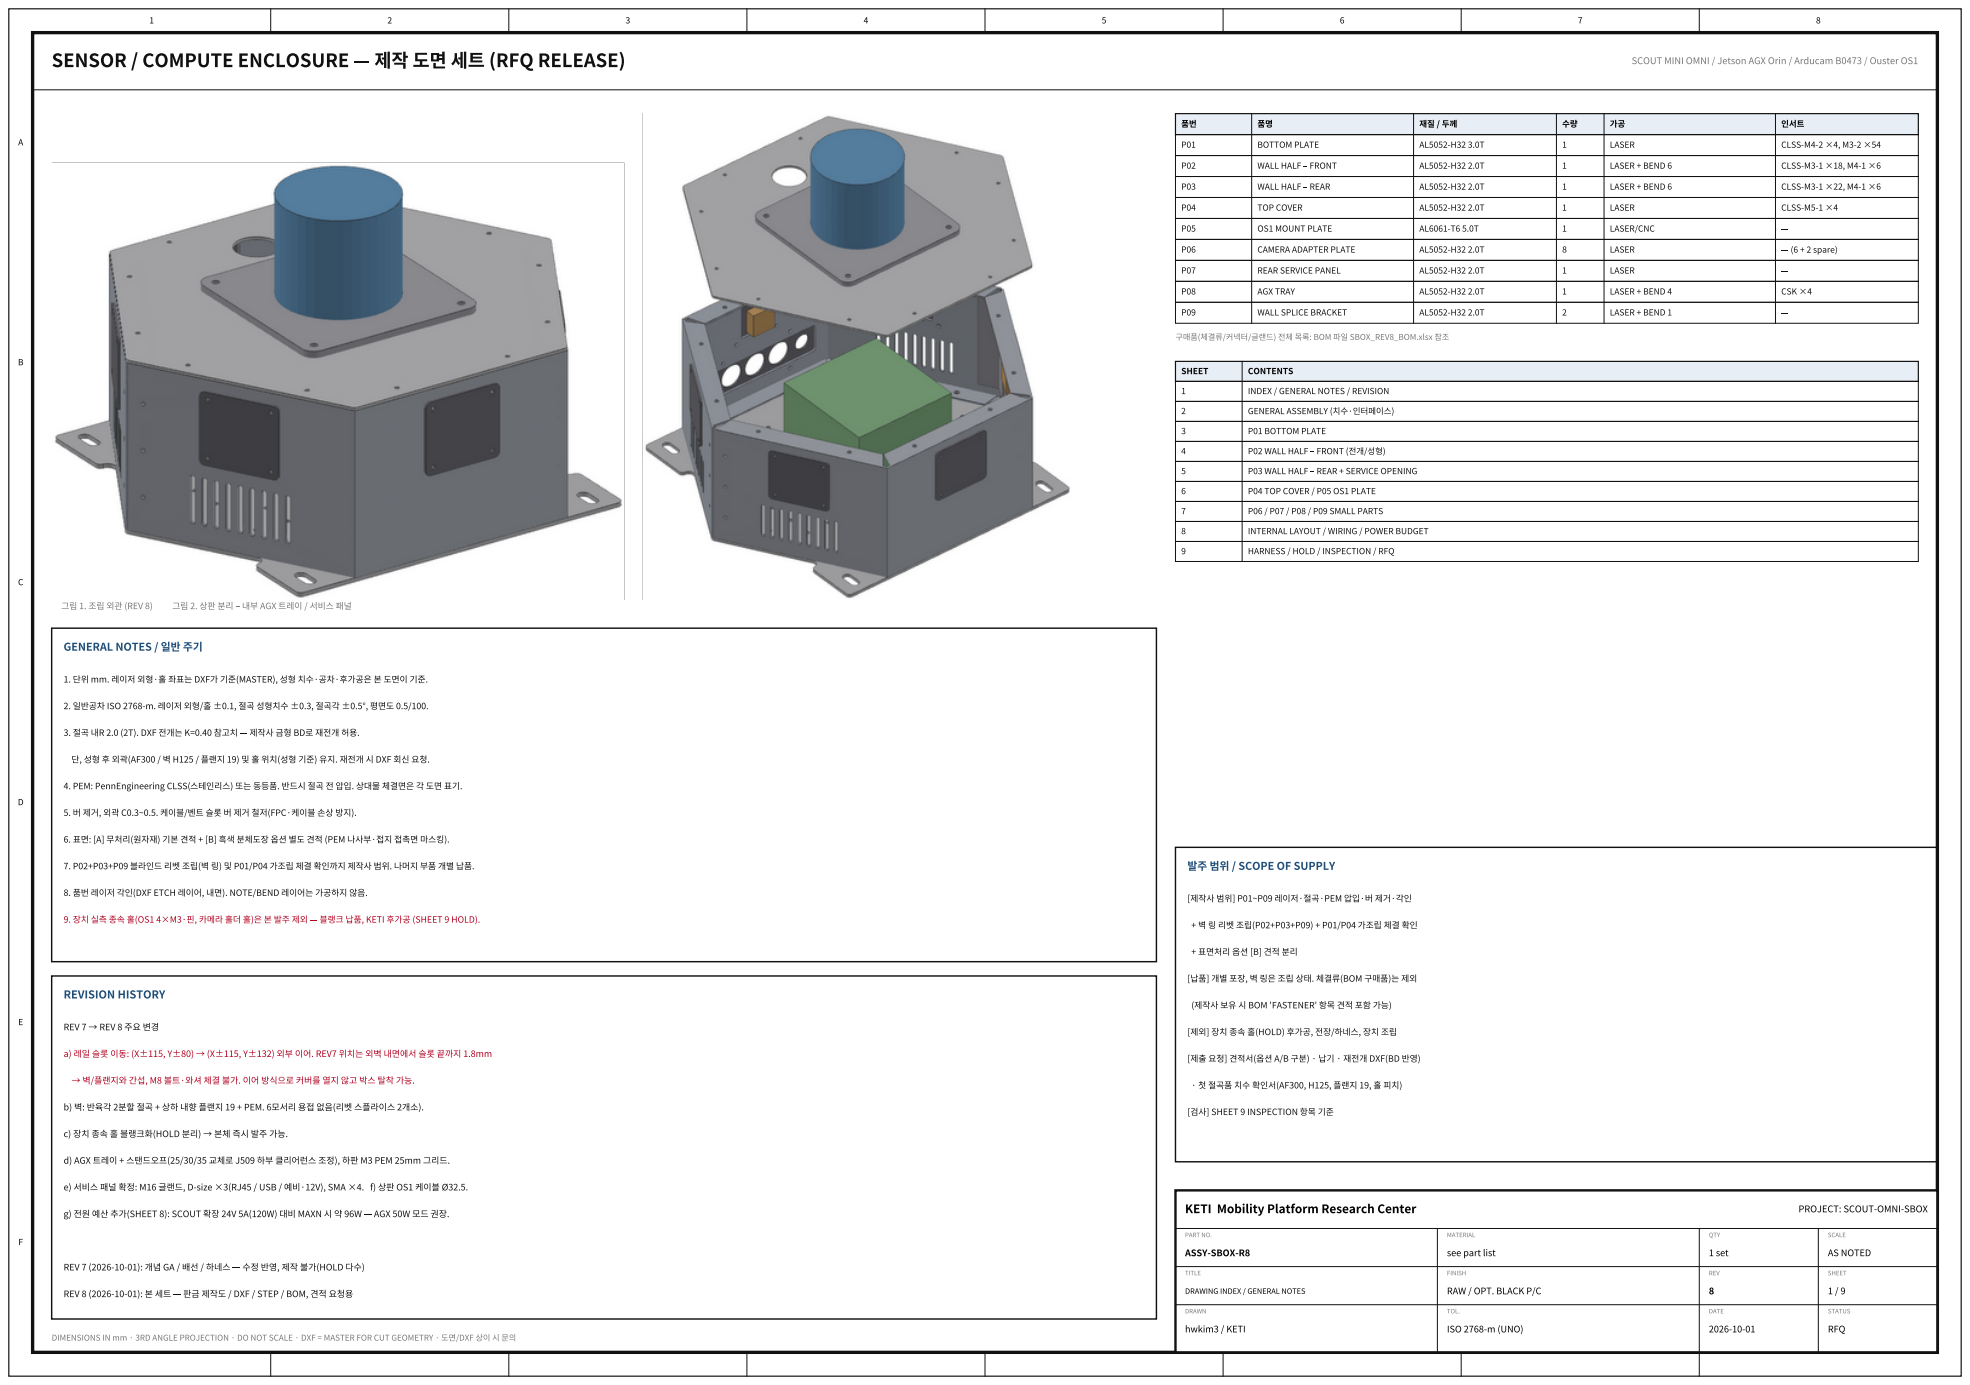
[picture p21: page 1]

# TOP VIEW (FRONT = +Y = C2) 1:3

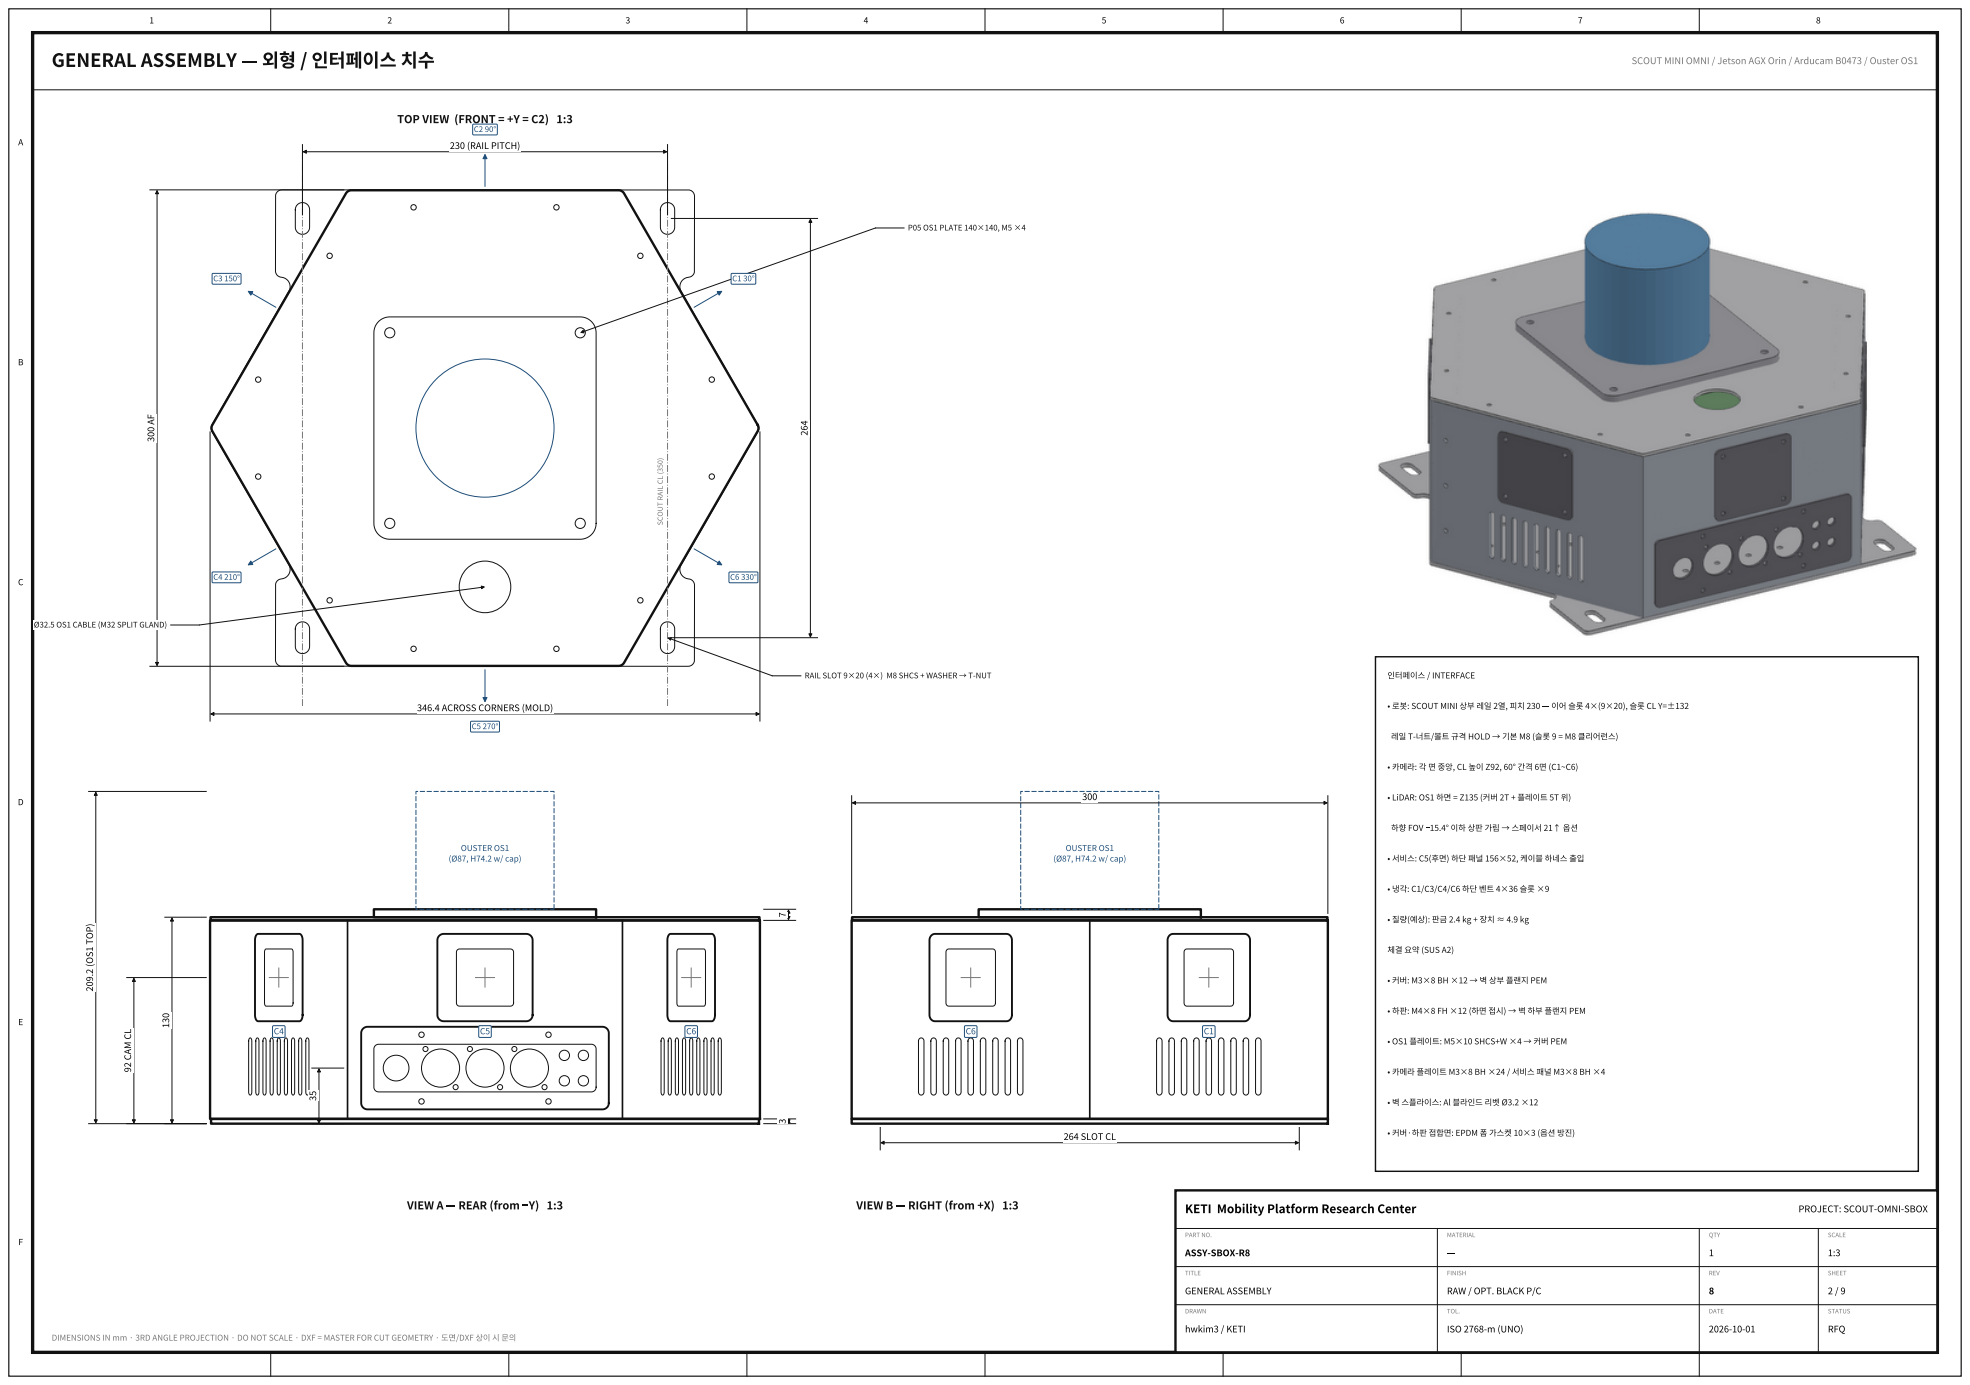
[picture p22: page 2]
GENERAL ASSEMBLY; SCOUT MINI OMNI / Jetson AGX Orin / Arducam B0473 / Ouster OS1; DIMENSIONS IN mm · 3RD ANGLE PROJECTION · DO NOT SCALE · DXF = MASTER FOR CUT GEOMETRY ·; /DXF; VIEW A REAR (from Y) 1:3; VIEW B RIGHT (from +X) 1:3; / INTERFACE; : SCOUT MINI; HOLD; LiDAR: OS1; FOV 15.4°; (SUS A2); PEM; : M5×10 SHCS+W ×4; : EPDM; KETI Mobility Platform Research Center; PROJECT: SCOUT-OMNI-SBOX; PART NO. ASSY-SBOX-R8; MATERIAL; QTY; SCALE; TITLE; REV 8; SHEET; DRAWN; hwkim3 / KETI; TOL.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

SCOUT RAIL CL (350)

Ø32.5 OS1 CABLE (M32 SPLIT GLAND)

346.4 ACROSS CORNERS (MOLD)

FINISH
RAW / OPT. BLACK P/C

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

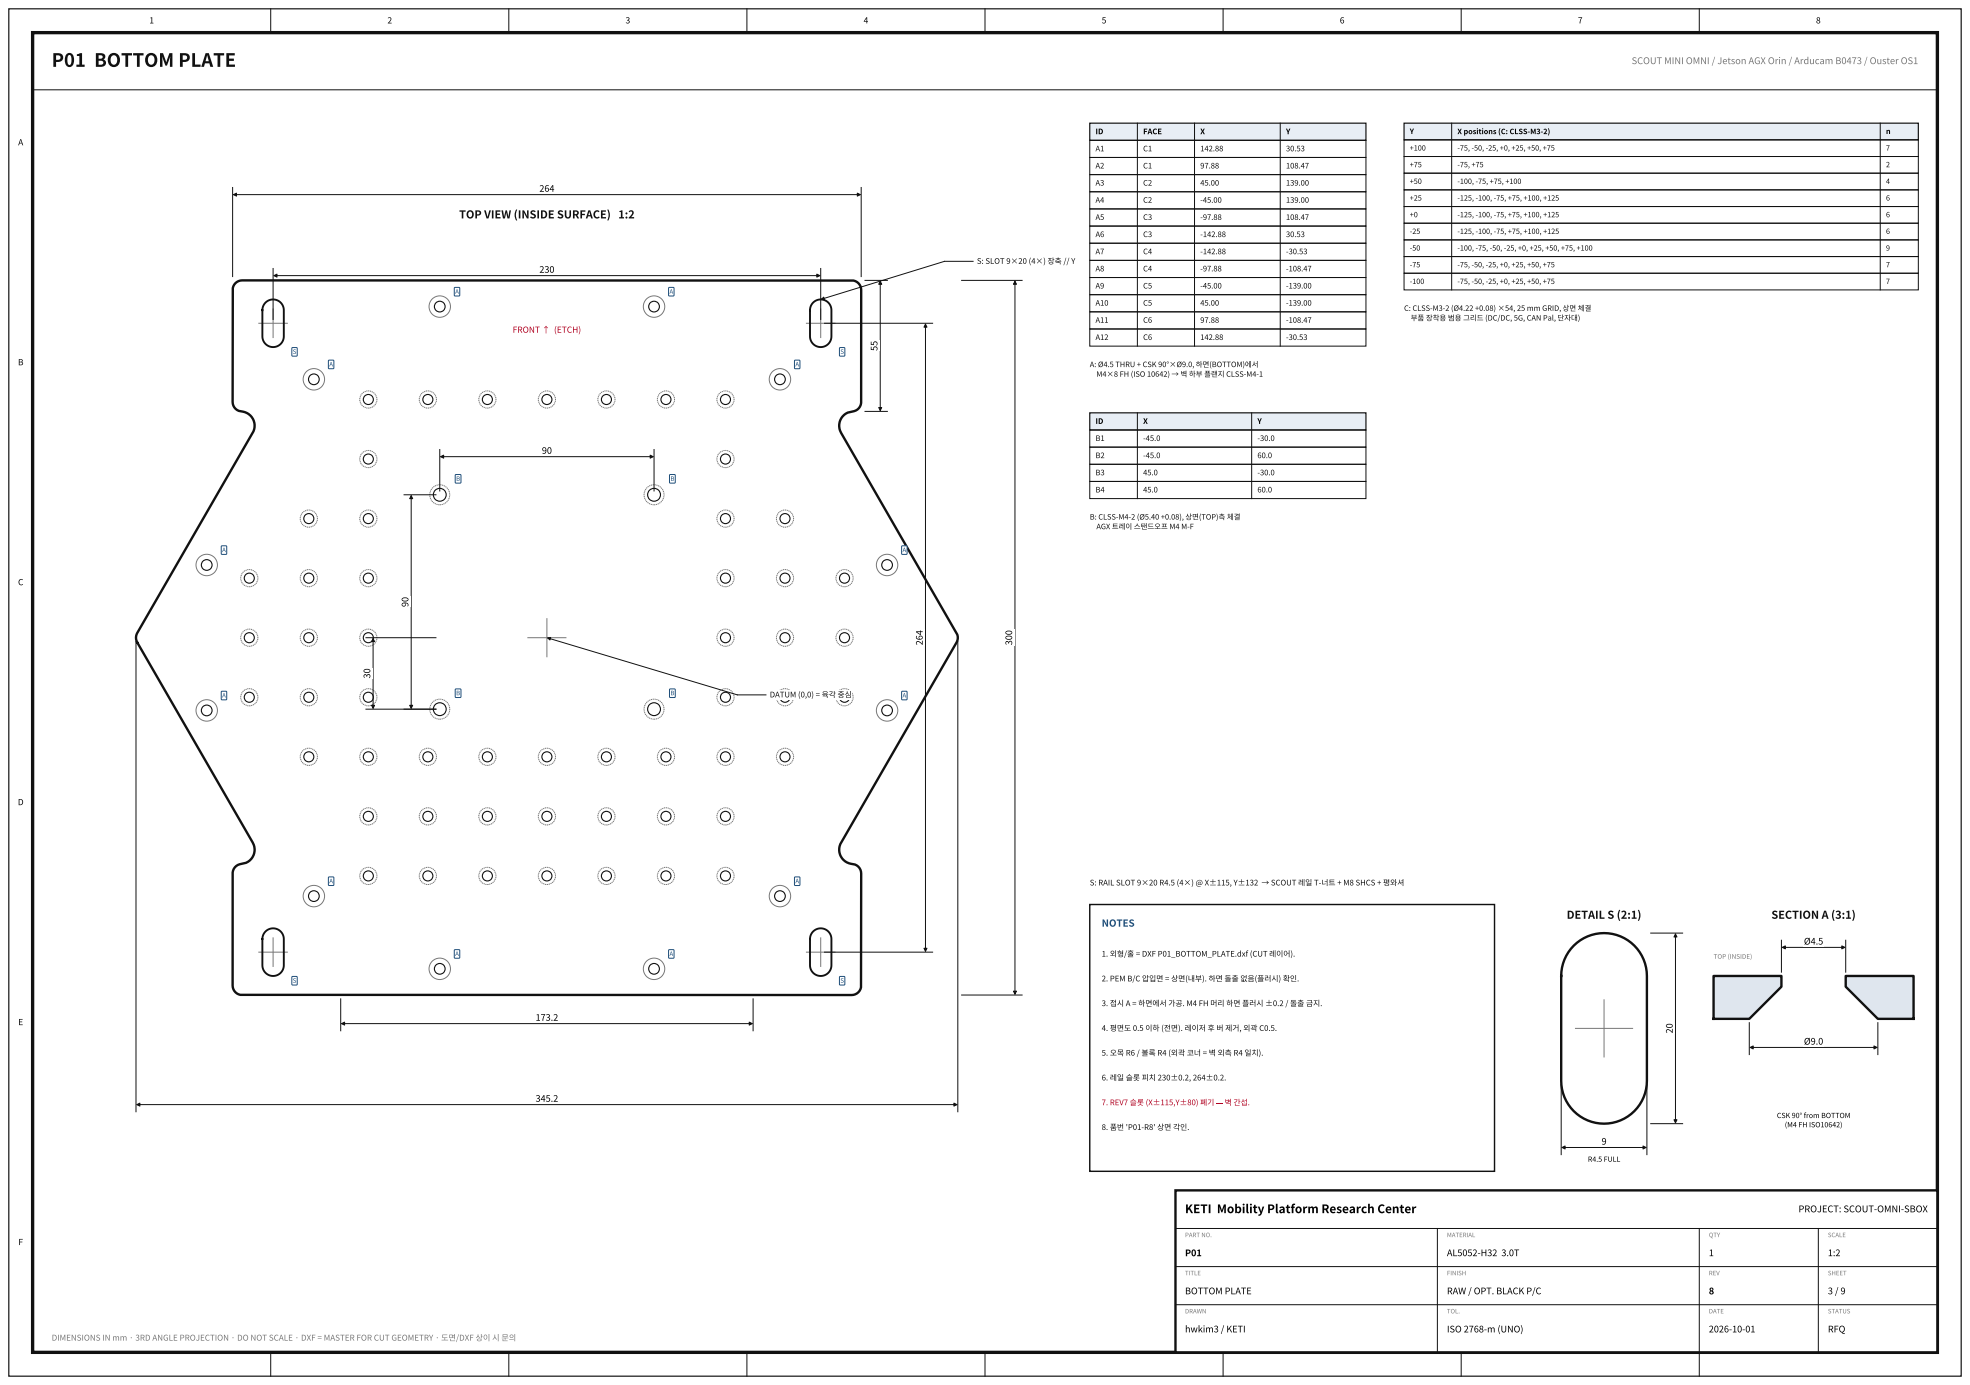
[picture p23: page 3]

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

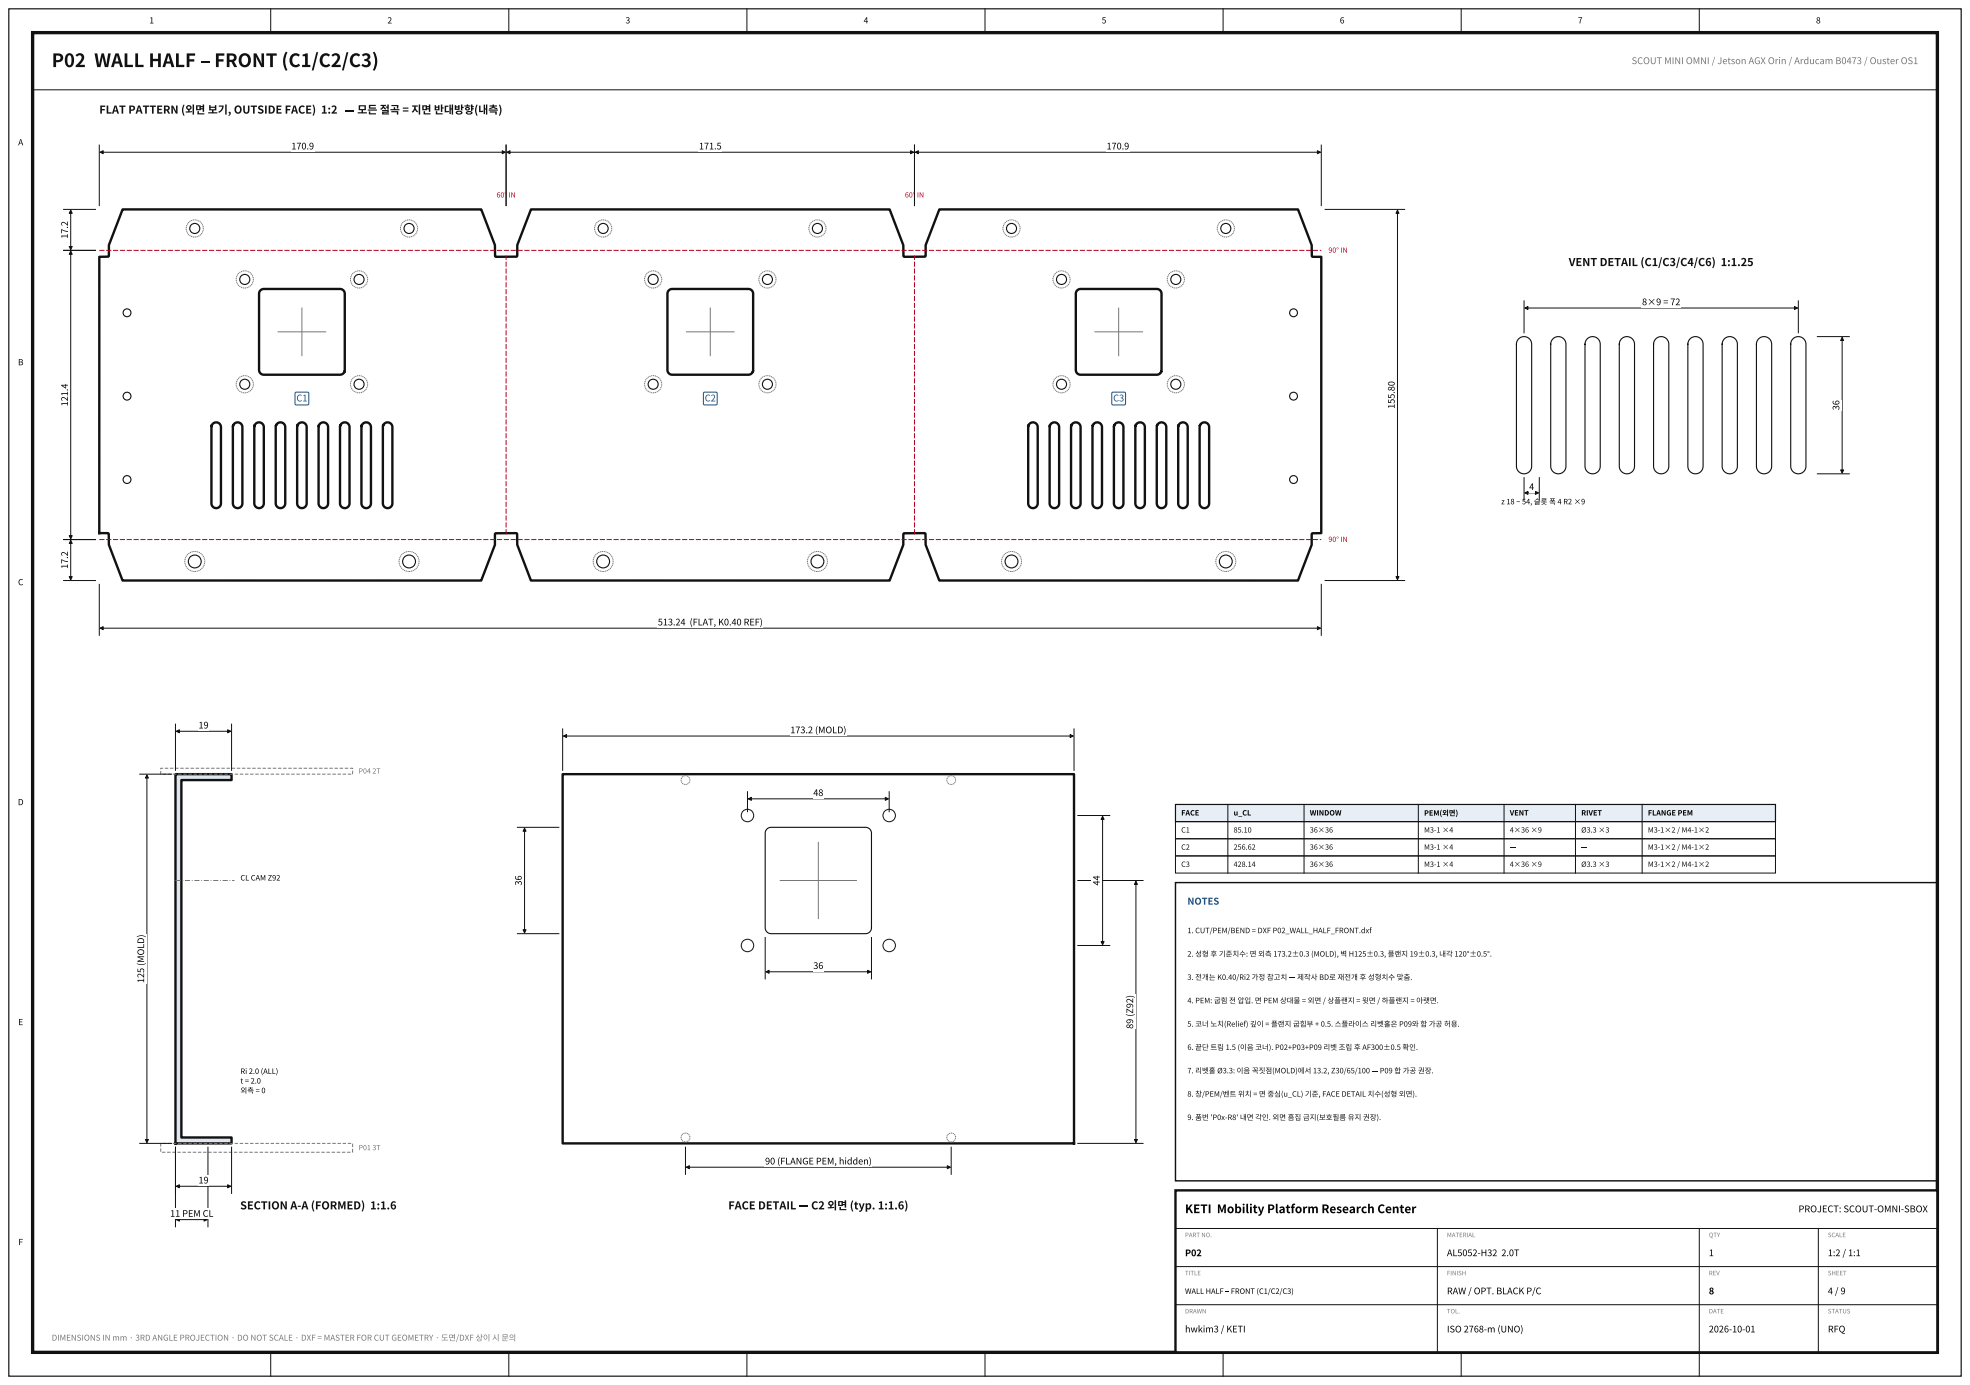
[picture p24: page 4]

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

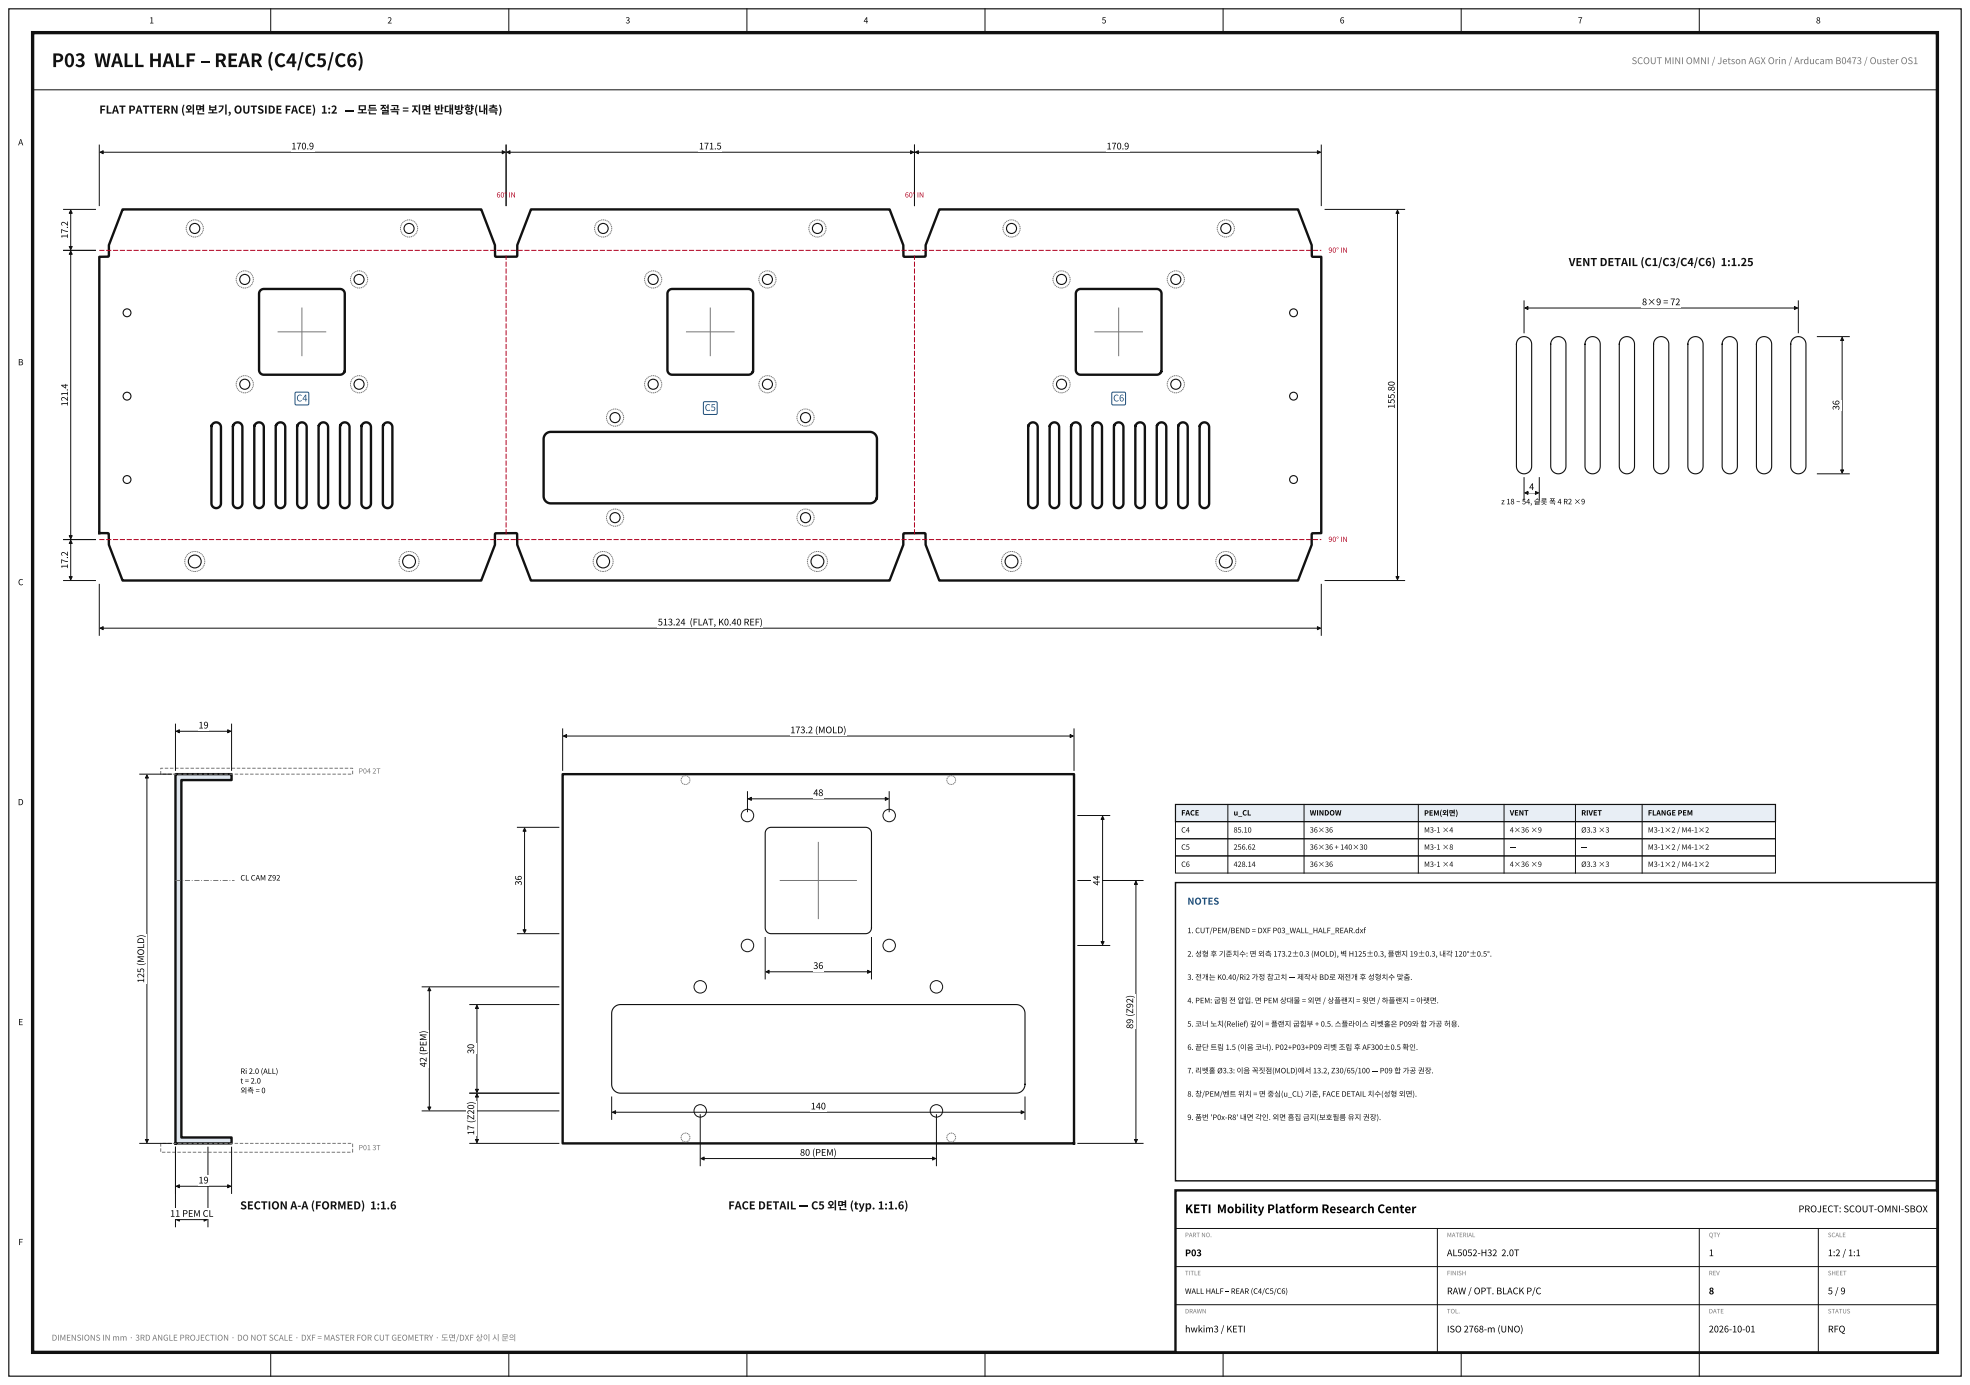
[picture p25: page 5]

# P04 TOP COVER TOP VIEW 1:2

ID | FACE | X | Y

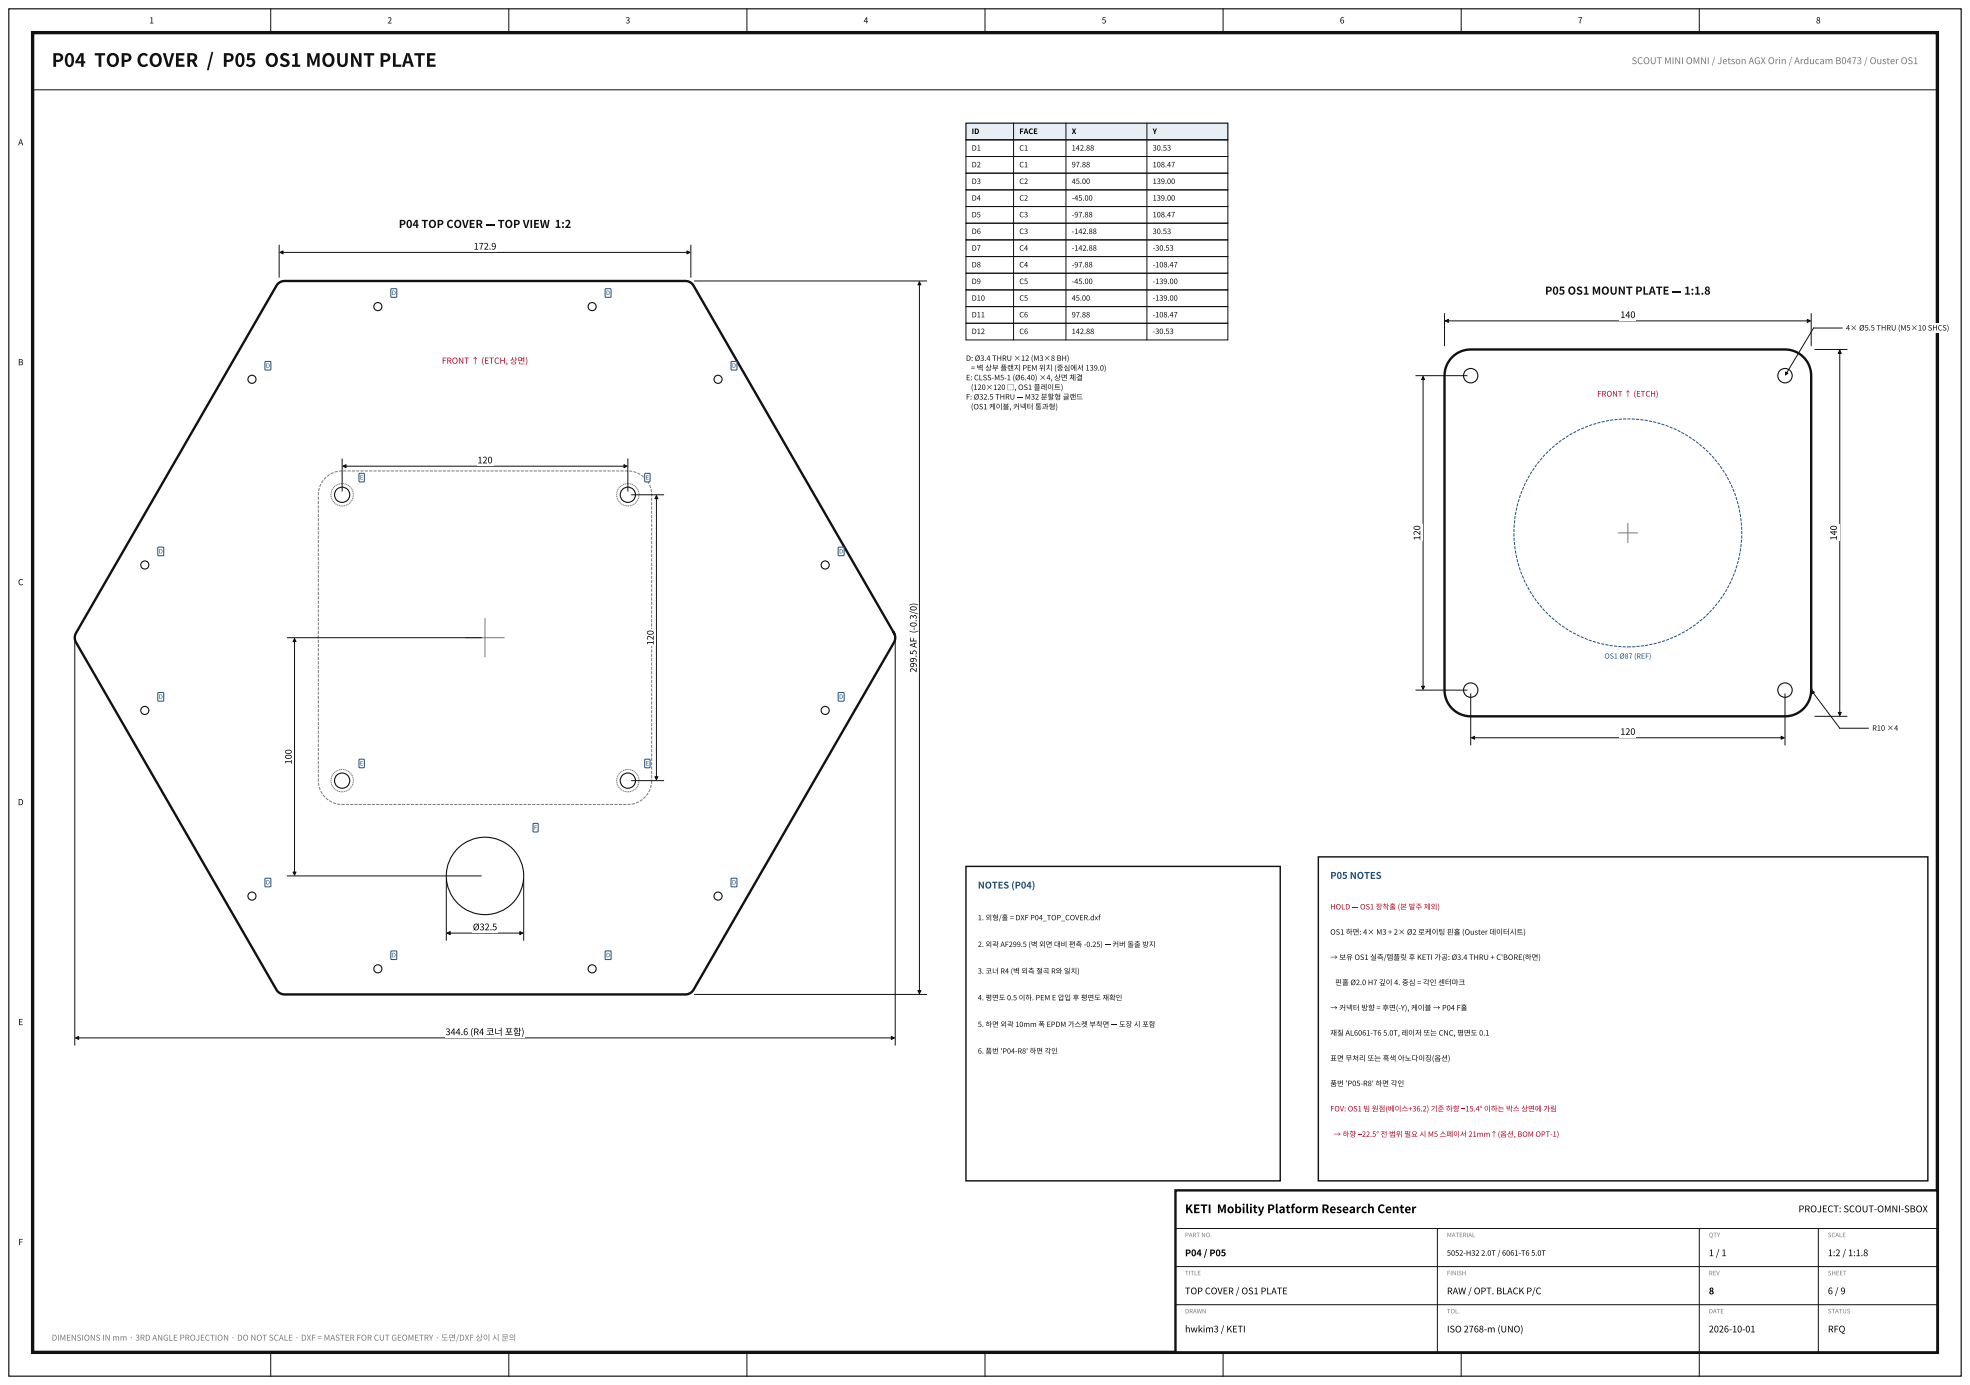
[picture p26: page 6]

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

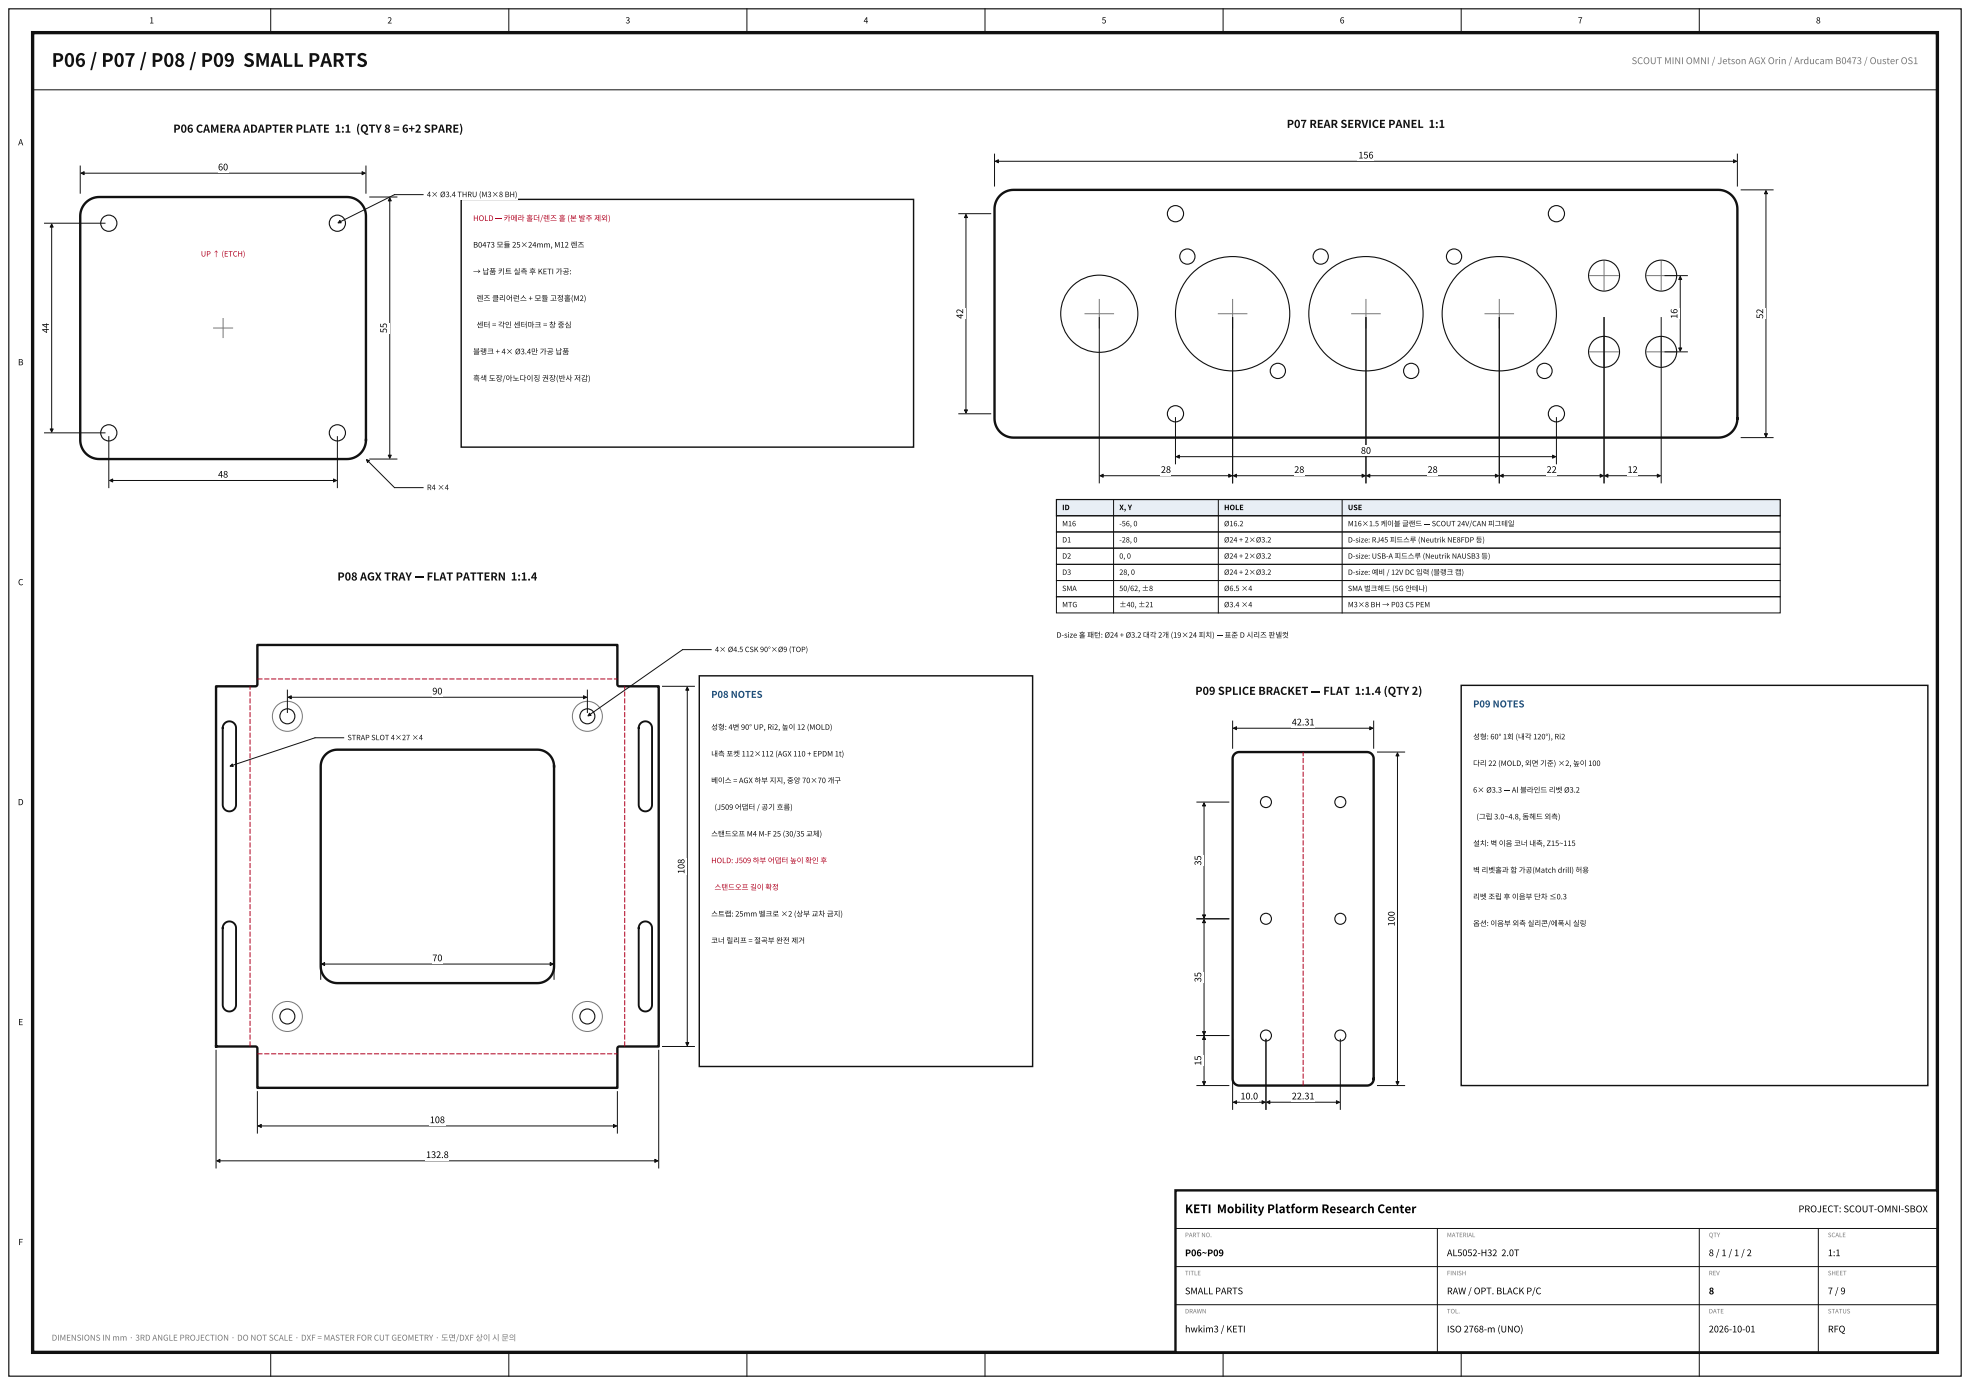
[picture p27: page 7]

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

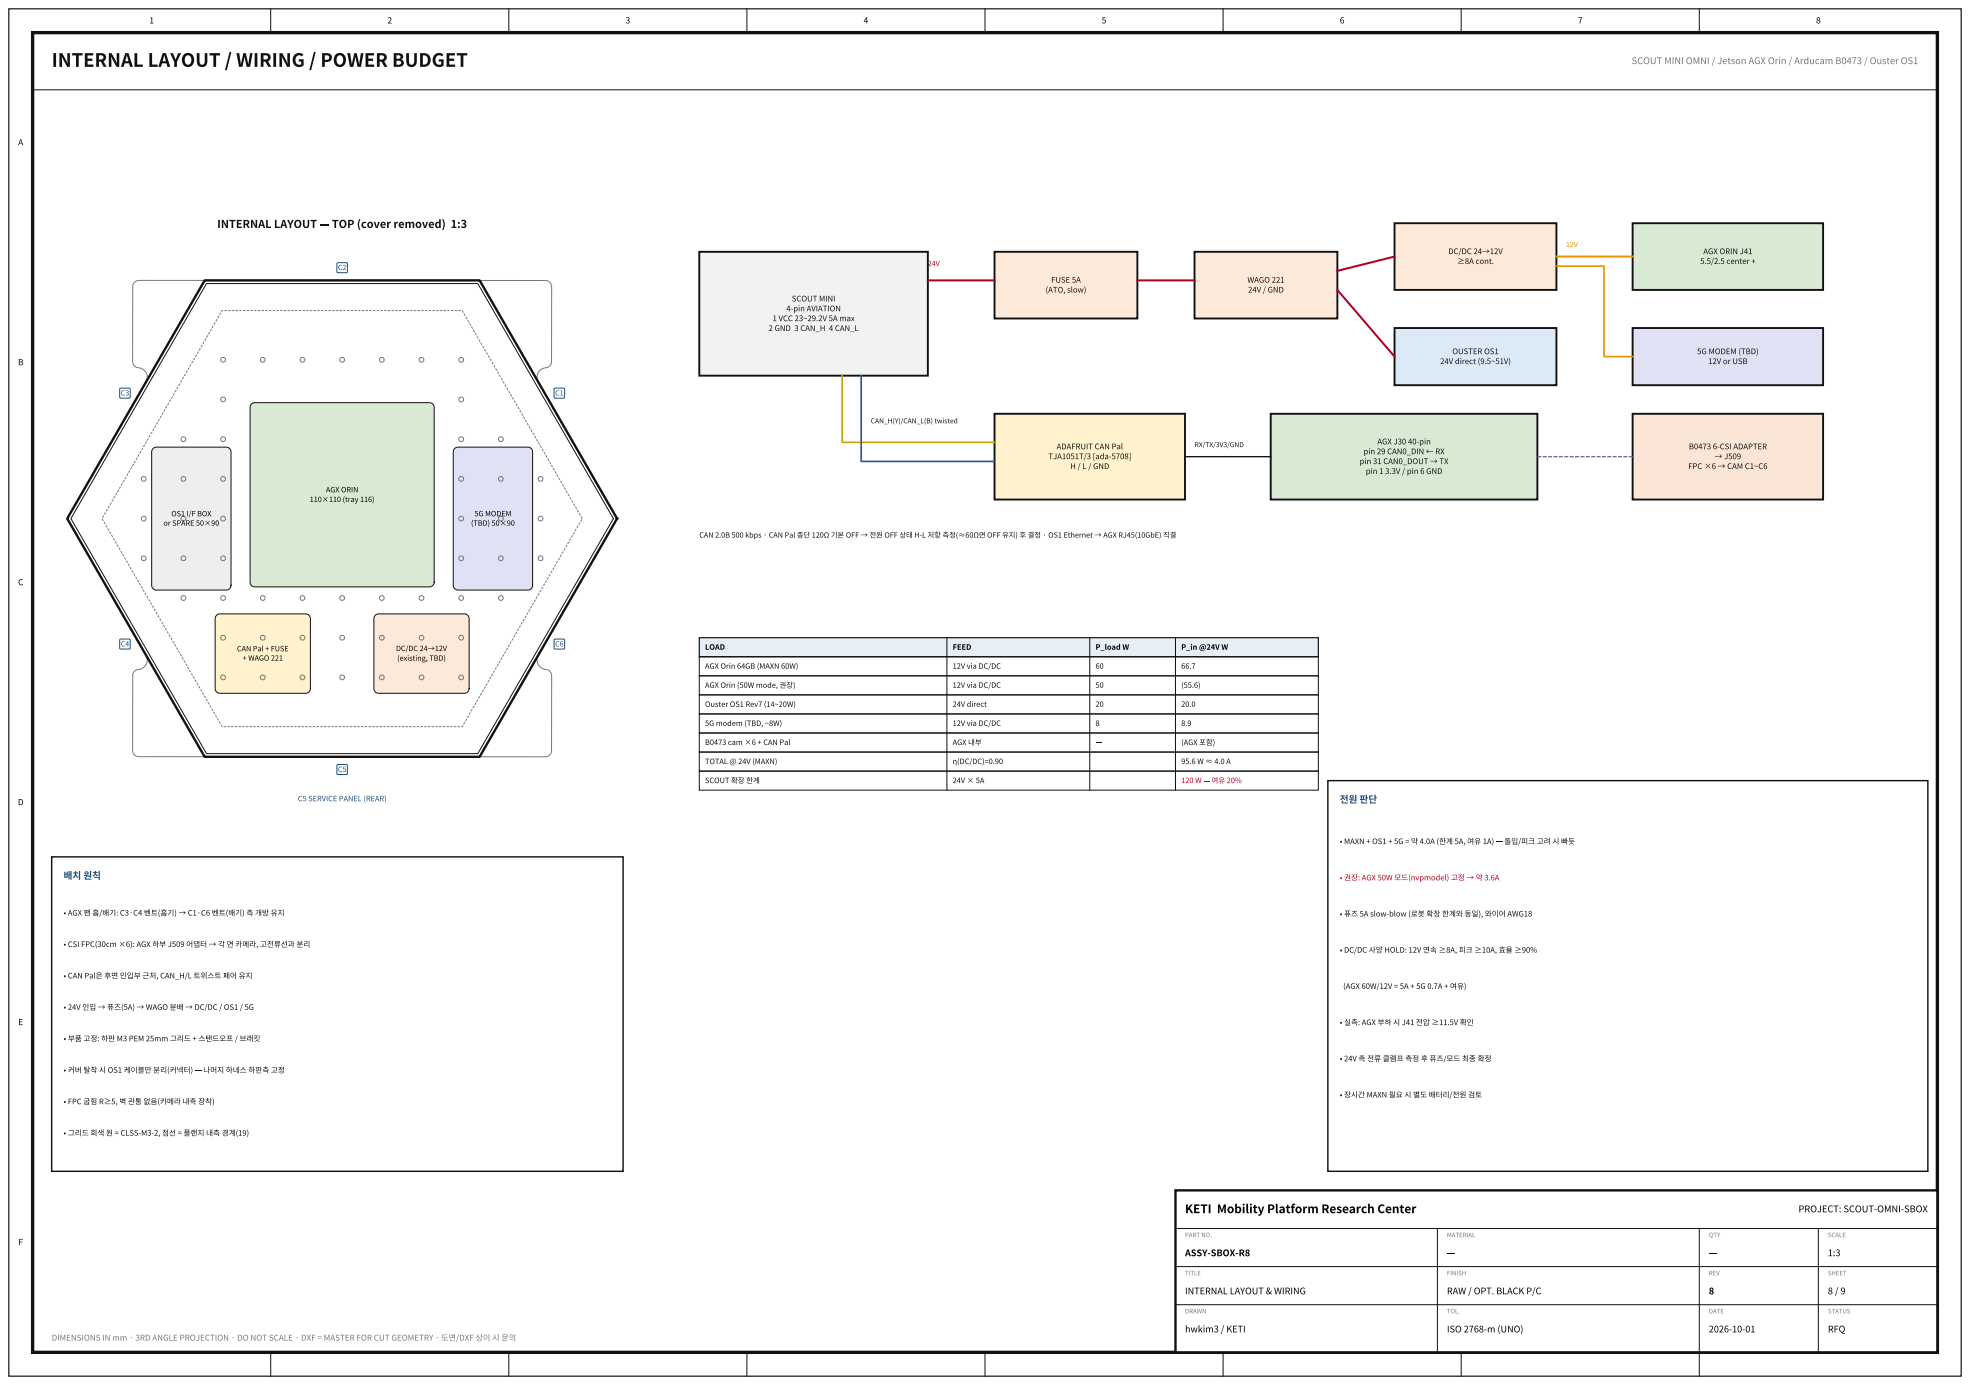
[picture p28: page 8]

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

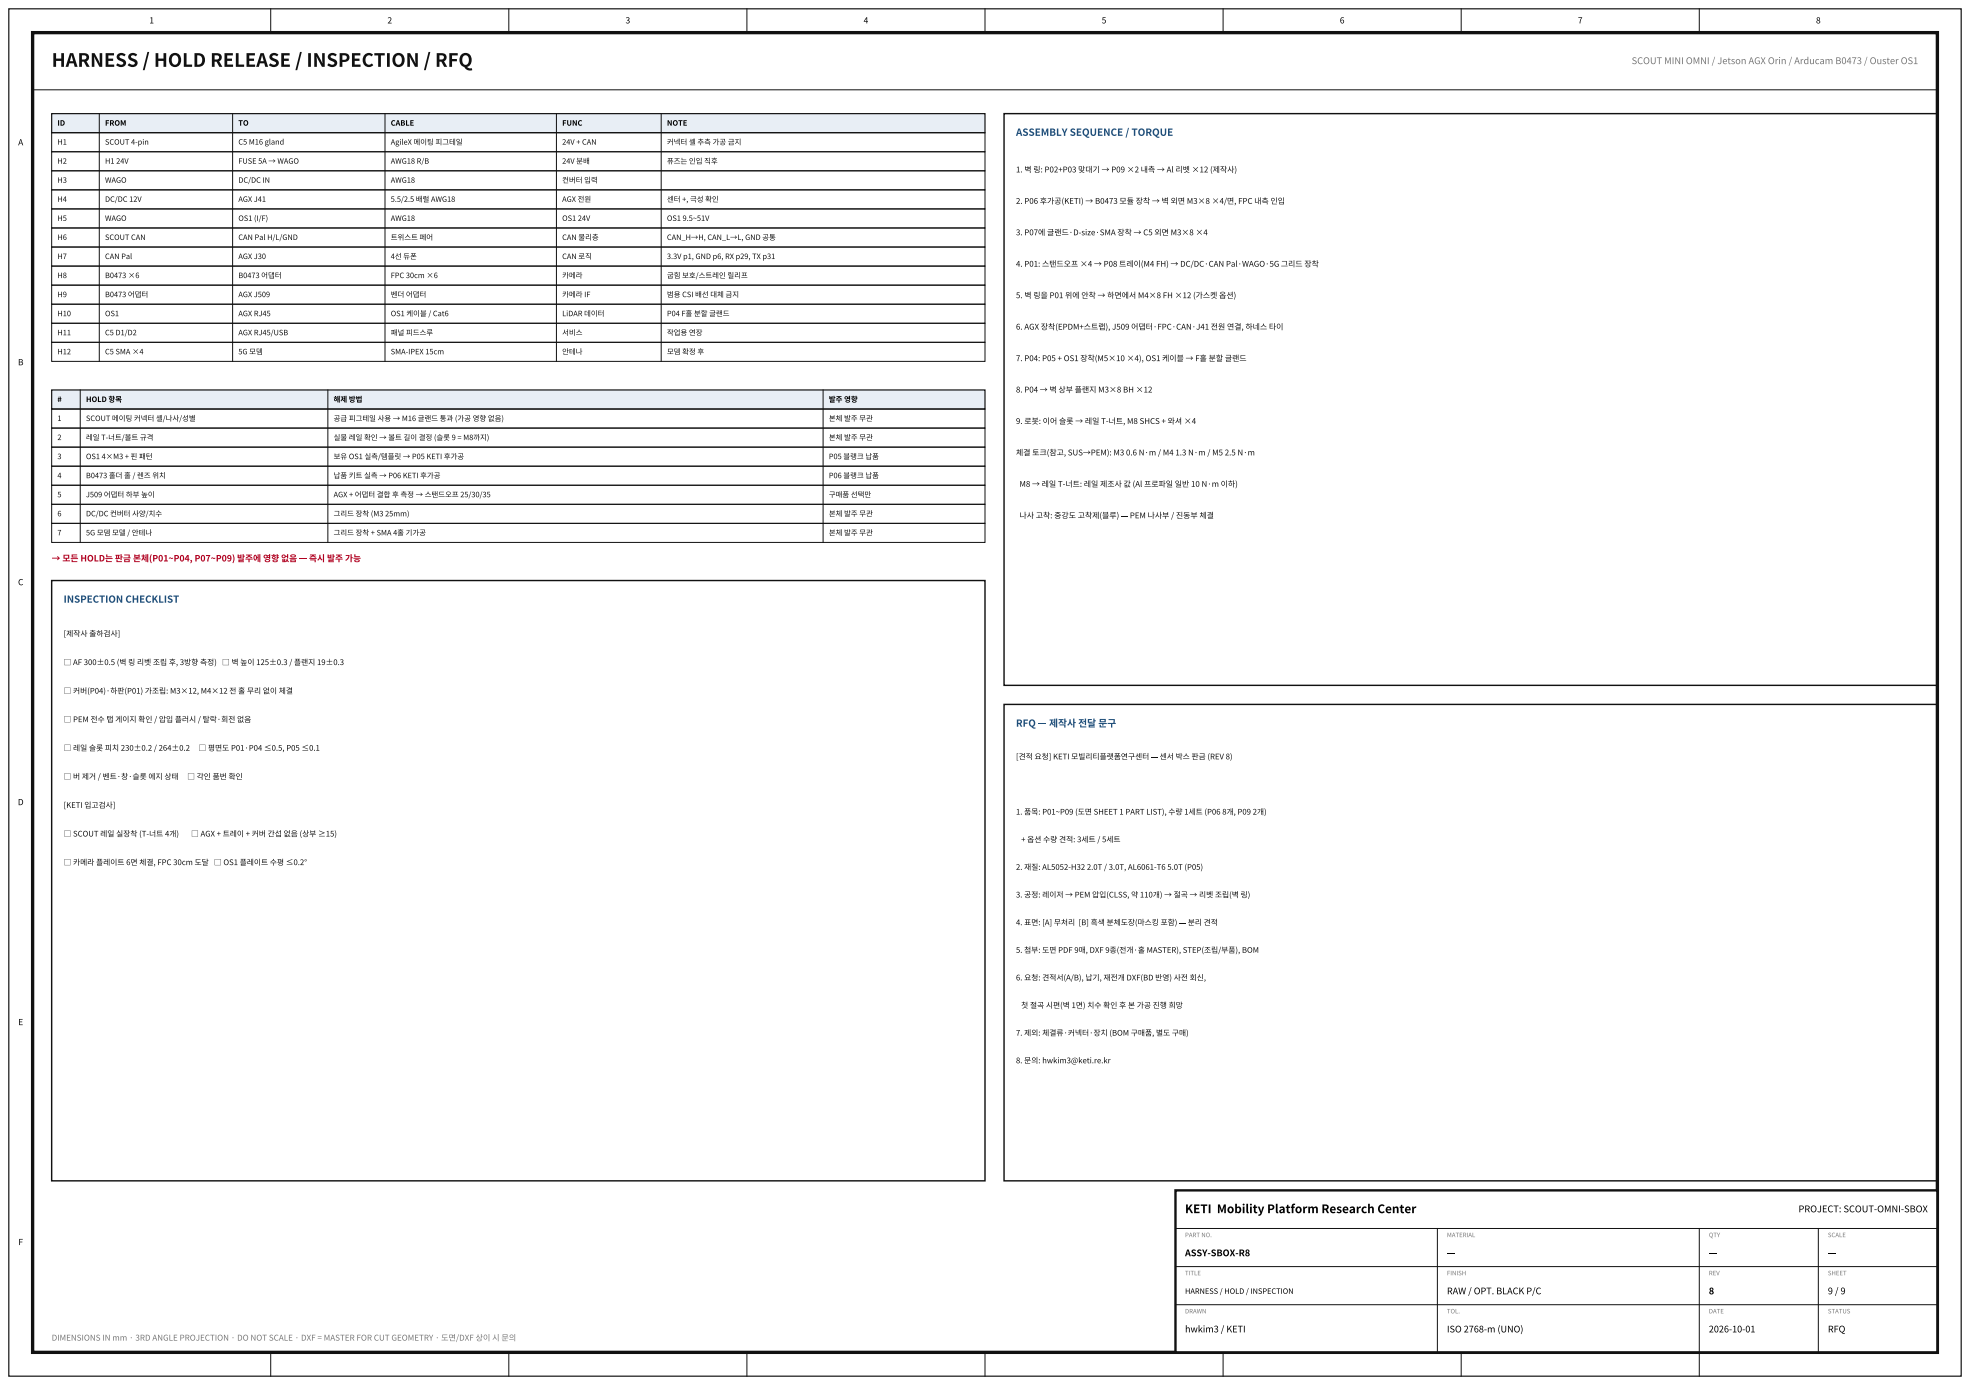
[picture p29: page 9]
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

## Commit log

2026-10-01 SBOX REV9 RFQ final: P10 e-plate, P11 OS1 riser, BARE masking, P08 clearance HOLD
    Claude-Session: https://claude.ai/code/session_01QuQ76tLZcwBitJJSmeNKWm
    [P01_BOTTOM_PLATE.dxf, P01_BOTTOM_PLATE.step, P02_WALL_HALF_FRONT.dxf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]
2026-10-01 REV9: rail pitch HOLD before P01 slot cut, expansion cable wording, FPC 60cm x2
    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
    [SBOX_REV9_BOM.xlsx]
2026-10-01 REV9: mating plug wording (WeGo inquiry)
    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
    [SBOX_REV9_BOM.xlsx]
2026-10-02 Add REFERENCES.md; HOLD 6: 24→19V converter for AGX as an alternative
    - REFERENCES.md: AgileX R&D Kit Pro, AGX Orin input range, Ouster OS1
    mounting/thermal, Orin closed-box thermal study (fan = REV 10 candidate),
    why the unofficial SolidWorks model can't release HOLD 2
    - HOLD 6 text in BOM and drawings: if the existing DC/DC is short of
    8 A, feed only the AGX from a 24→19 V converter (7–20 V input)
    - Regenerated BOM and drawing PDF
    [SBOX_REV9_BOM.xlsx]
2026-10-27 REV10-P design brief (printed PETG variant for a 256 mm bed: round one-piece body, lid, rail plate, replaceable camera plates) and a Bambu preset flattener for CLI slicing
2026-10-27 REV10-P v1: flat-panel hexagon for the Bambu A1 (6 panels, 6 posts, floor, rail bars, camera plates) with clearance/screw checks and sliced PLA files
2026-10-27 REV10-P: camera mount from the measured camera (red holder in the wall window, clear part through the plate, M2 34.1x29.0) + 25-min camera test print
2026-10-27 REV10-P: square-cornered camera plate opening (camera test fit)
2026-10-27 REV10-P: reslice camera plates
